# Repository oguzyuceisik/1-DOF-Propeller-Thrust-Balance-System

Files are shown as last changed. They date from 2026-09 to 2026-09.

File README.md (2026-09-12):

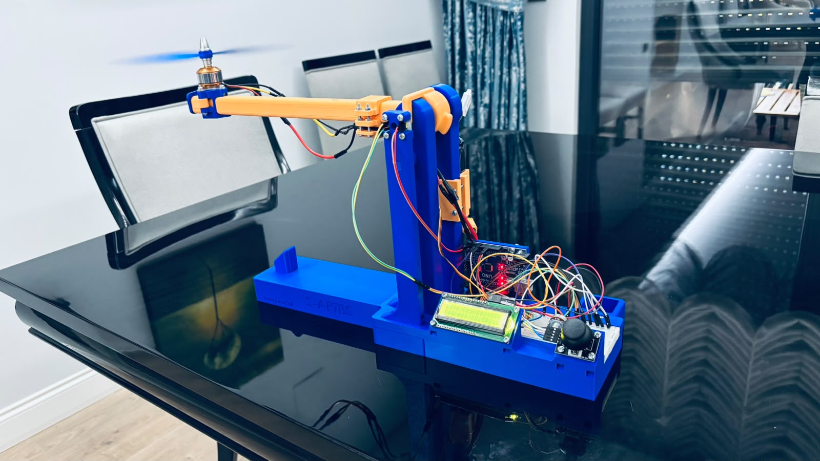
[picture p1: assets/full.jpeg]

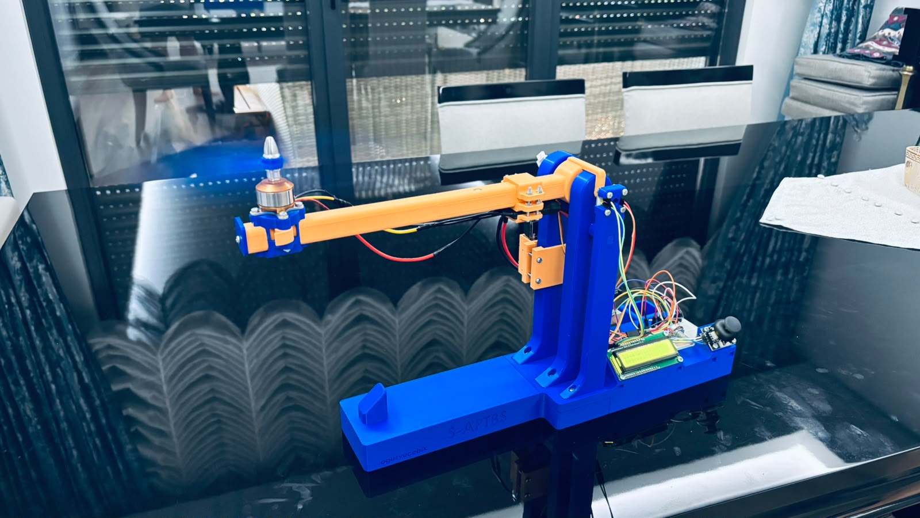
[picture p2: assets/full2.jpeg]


# 1-DOF-Propeller-Thrust-Balance-System

A 1-Degree-of-Freedom (1-DOF) closed-loop thrust balance arm controlled by a Brushless DC motor and an AS5600 12-bit magnetic rotary encoder, powered by an Arduino.

---

## Overview
This project demonstrates closed-loop attitude control of a thrust-balanced lever arm. A custom PID controller runs at a deterministic 50 Hz (`dt = 0.02s`), stabilizing the arm against gravity at any desired angle. System parameters ($K_p, K_i, K_d$, and Target Angle) can be adjusted in real time via a 2-axis analog joystick and an interactive 1602 LCD menu without interrupting the control loop.

---

## Features
- **Deterministic Loop Timing:** Control loop executes strictly at 50 Hz using non-blocking timer logic.
- **Custom Modular PID Implementation:** Written natively in C and wrapped as a C++ source file (`saptbsPID.cpp` / `saptbsPID.h`) for seamless compilation with the Arduino toolchain.
- **Integral Anti-Windup:** Prevents integrator saturation and aggressive overshoot using strict clamping boundaries ($\pm750\,\mu s$).
- **Base Actuator Offset:** Actuator output is mapped cleanly onto standard ESC pulse widths ($1000 - 2000\,\mu s$).
- **Live Telemetry & Interactive Menu:** Real-time angle monitoring and on-the-fly gain scheduling via a 1602 LCD and analog joystick.
- **Mechanical CAD Package:** Complete 3D printable files (`.stl`) and universal exchange models (`.step`) for the chassis, pivot bearings, M3 thread, and motor lever arm.

---

## Hardware Architecture

| Component | Specification | Function |
| :--- | :--- | :--- |
| **Microcontroller** | Arduino Uno | Main control loop, sensing, and ESC PPM generation |
| **Feedback Sensor** | AS5600 12-bit Rotary Encoder | Contactless angle measurement via I2C |
| **Actuator** | Brushless Motor + Propeller | Dynamic thrust generation |
| **ESC** | 30A Brushless ESC | Motor driving |
| **Interface** | 1602 Character LCD | Live telemetry display and tuning interface |
| **Input** | 2-Axis Analog Joystick Module | Menu navigation and runtime parameter updates |

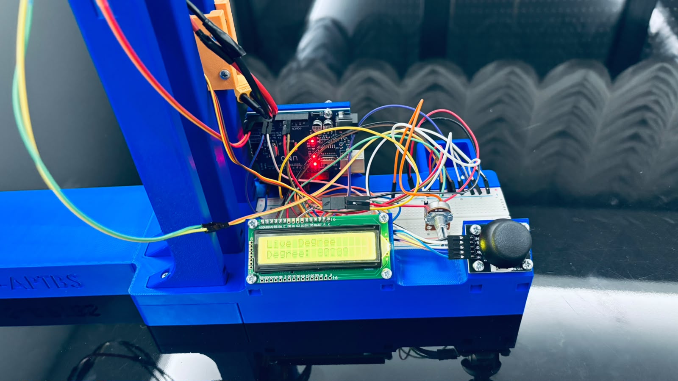
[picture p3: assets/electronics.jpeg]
Hardware

---

## Pinout Configuration

| Peripheral | Arduino Pin 
| **ESC Signal** | D6 
| **AS5600 SDA** | A4 
| **AS5600 SCL** | A5 
| **Joystick X-Axis** | A0 
| **Joystick Y-Axis** | A1 
| **Joystick Button** | D2 
| **LCD RS, EN** | D7, D8 
| **LCD D4 - D7** | D9, D10, D11, D12

---

## Mechanical & CAD Files
The complete physical assembly files are provided under the `/cad` directory:
- **`cad/stl/`**: Ready-to-print meshes for 3D printers (PLA or PETG recommended, %10-%15 infill).
- **`cad/step/`**: Universal CAD files for modification in SolidWorks.

---

## CAD PREVIEW

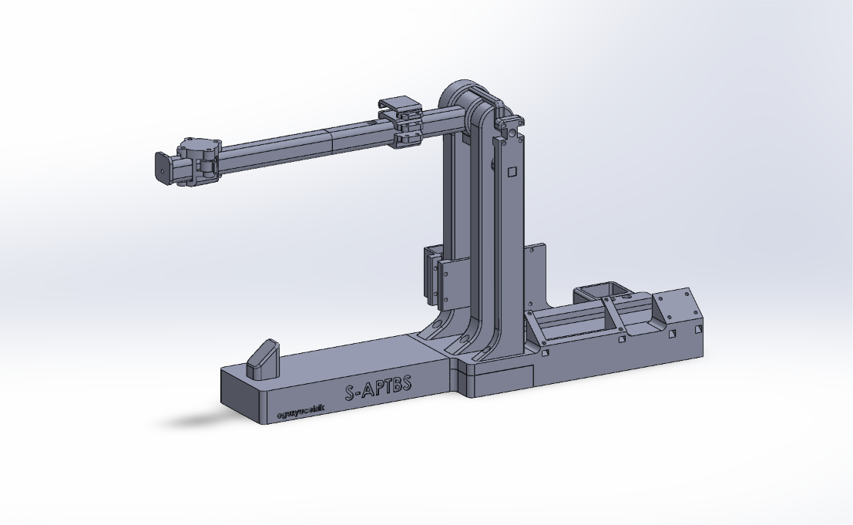
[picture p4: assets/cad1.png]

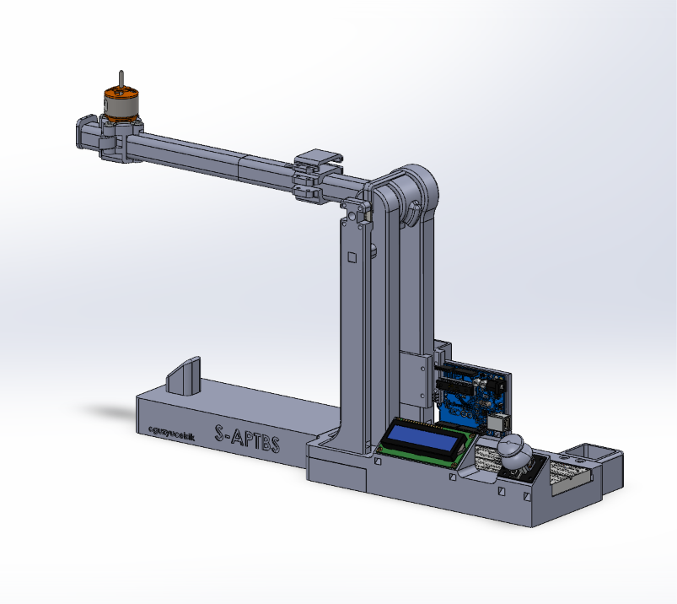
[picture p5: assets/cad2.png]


---

## Getting Started

1. Clone or download this repository.
2. 3D print the mechanical components from `/cad/stl` and assemble the pivot arm with the AS5600 diametric magnet axially centered.
3. Install the required Arduino libraries via Library Manager:
   - `Servo`
   - `Wire`
   - `LiquidCrystal`
   - `AS5600`
4. Connect the hardware according to the pinout table above.
5. Power the ESC with a 3S LiPo battery. The built-in 5V BEC supplies logic power to the Arduino and all connected peripherals.
6. Upload the `.ino` sketch to your Arduino board.
7. Wait 2 seconds during startup for the ESC arming sequence.
8. Use the joystick to navigate the LCD menu, adjust $K_p, K_i, K_d$ on the fly, and command target angles.

---

## MEDIA:
Demo Video (https://www.youtube.com/watch?v=CsmWMHaqUeA)

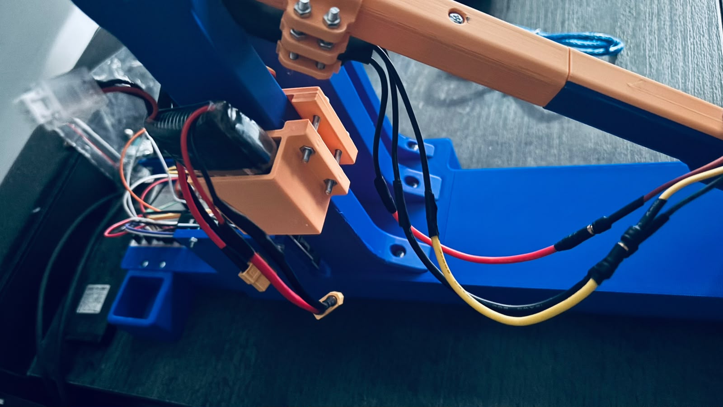
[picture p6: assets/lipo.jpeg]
LiPo Photo

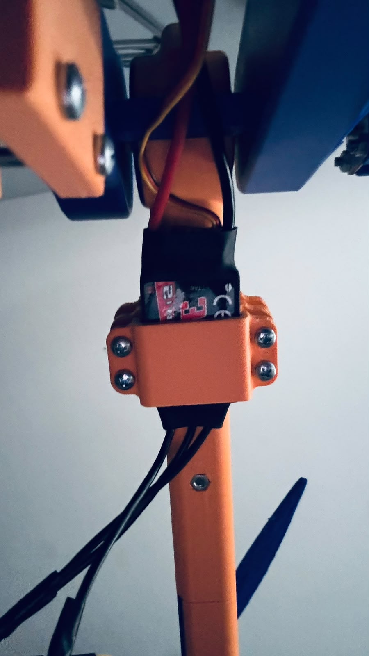
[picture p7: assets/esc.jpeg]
ESC Photo

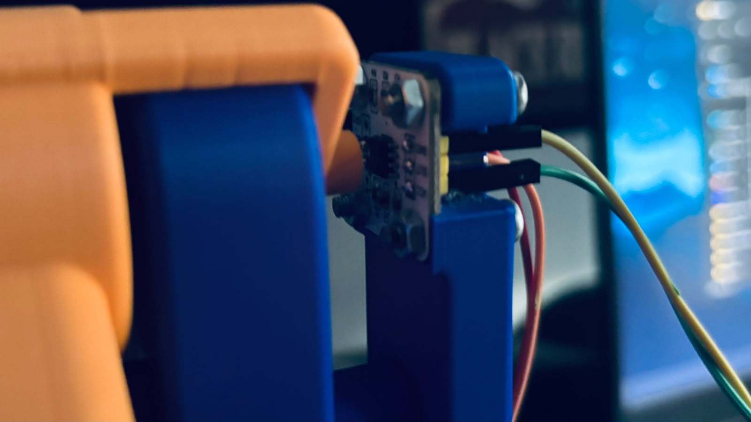
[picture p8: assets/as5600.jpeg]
AS5600 PHOTO


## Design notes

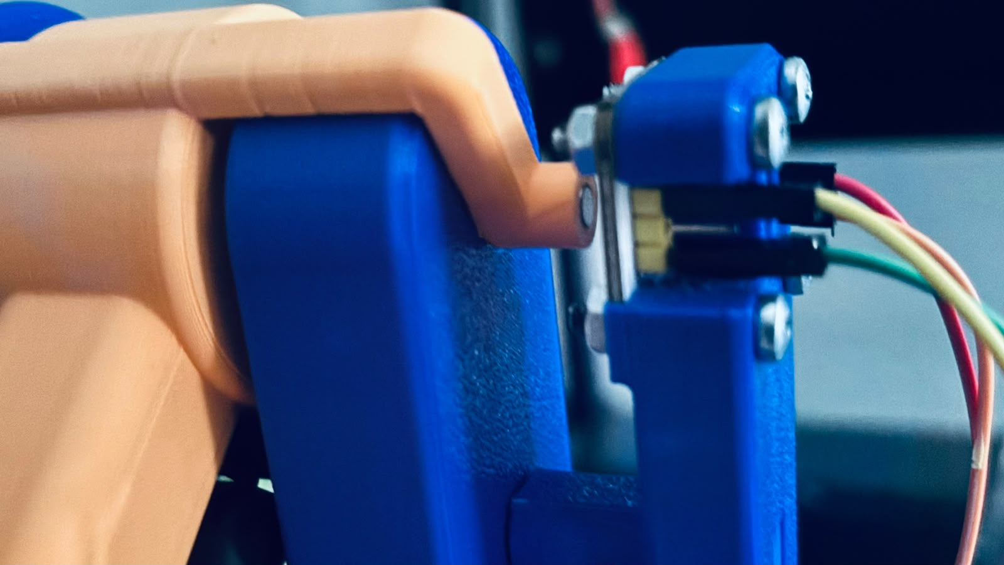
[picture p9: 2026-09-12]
assets/as5600 magnet.jpeg

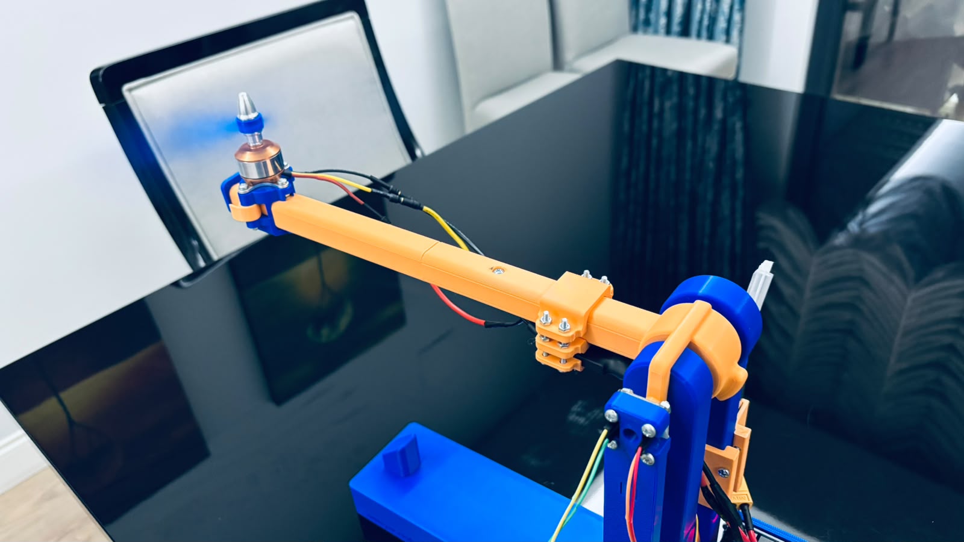
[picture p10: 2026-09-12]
assets/propeller.jpeg

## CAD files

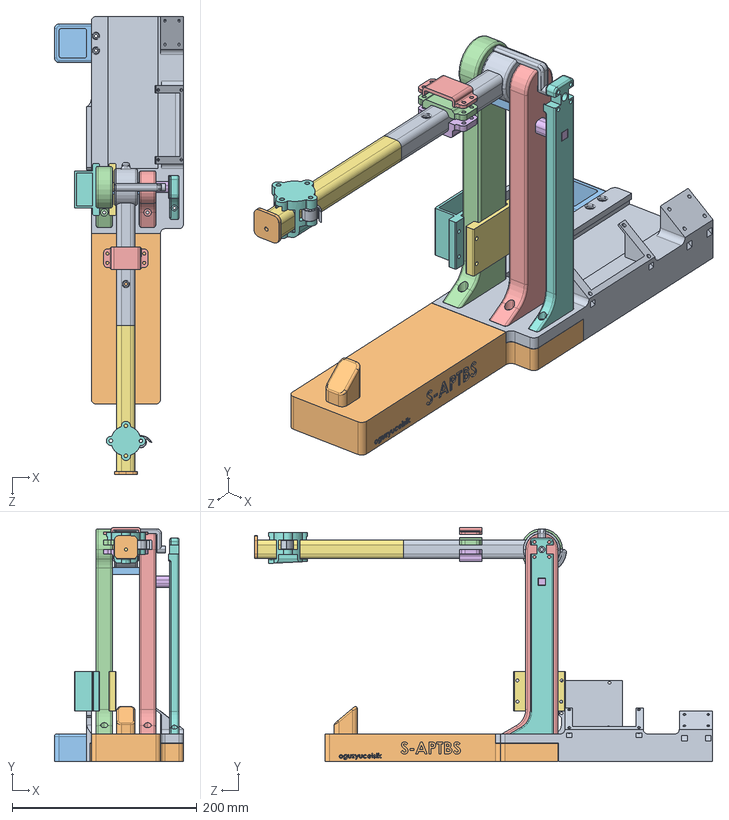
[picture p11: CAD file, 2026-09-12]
saptbsPID_CAD/SAPTBSassembly.STEP
140.0 x 254.0 x 496.4 mm
BaseParts
Leg1
6801ZZ_12x21x5_5972K154_Steel Ball Bearing_5972K154 x 2
LockIN
MotorBase
propellerLock
ArmLock
BatteryBed
ESCHolder
LiPoHolder

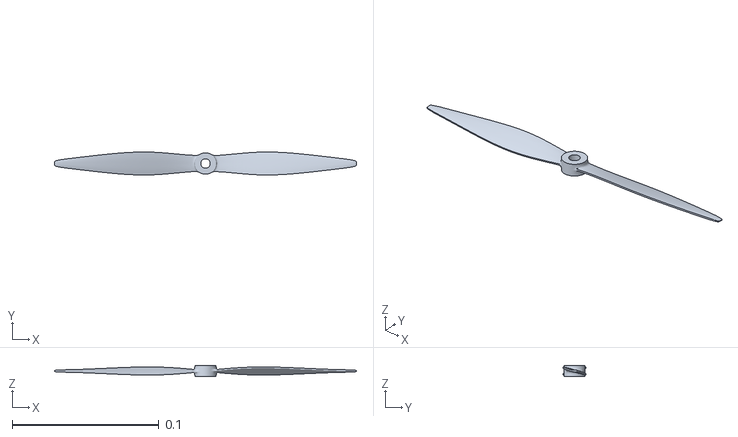
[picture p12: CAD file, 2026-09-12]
saptbsPID_CAD/propeller1.stl
0.206 x 0.0157 x 0.0075

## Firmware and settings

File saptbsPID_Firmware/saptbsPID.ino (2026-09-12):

#include "saptbsPID.h"
#include <Servo.h>
#include <Wire.h>
#include <AS5600.h>
#include <LiquidCrystal.h>


PIDsetup motor;
const uint8_t escPin = 6;

const uint8_t rs = 7;
const uint8_t en = 8;
const uint8_t d4 = 9;
const uint8_t d5 = 10;
const uint8_t d6 = 11;
const uint8_t d7 = 12;

const uint8_t xPin = A0;
const uint8_t yPin = A1;
const uint8_t jButton = 2;
int xVal;
int yVal;

int allow = 1;
int prev_allow = -600;

float kp = 6.f;
float kd = 3.0f;
float ki = 1.f;

float liveAngle = 0.0f;

float prev_kp = -600;
float prev_ki = -600;
float prev_kd = -600;
int prev_target = -600;

int i = 0;
int prev_i = -1;

String menus[5][2] = {{"Live Degree" , "Degree"},

                      {"Parameters", "Kp"},

                      {"Parameters", "Ki"}, 

                      {"Parameters", "Kd"}, 

                      {"Target", "Degree"}
};


byte upDownArrow[8] = {
  B00100,
  B01110,
  B11111,
  B00000,
  B11111,
  B01110,
  B00100,
  B00000
};

LiquidCrystal lcd(rs, en, d4, d5, d6, d7);

float target = 654.0f * (360./4095.);

AS5600 as5600;
unsigned long lasTime = 0;
unsigned long lastLCDTime = 0;
const int inputDelay = 250;


Servo esc;

void setup(){
  Wire.begin();
  as5600.begin();

  lcd.begin(16, 2);
  lcd.createChar(1, upDownArrow);
  pinMode(xPin, INPUT);
  pinMode(yPin, INPUT);
  pinMode(jButton, INPUT_PULLUP);

 Serial.begin(9600);

  esc.attach(escPin, 1000, 2000);
  pid_setup(&motor, kp, ki, kd,  2000, 1000);

  esc.writeMicroseconds(1000);
  delay(2000);

}

void loop(){

  lcdControl();
  
  unsigned long currentTime = millis();
  float dt = (currentTime - lasTime) / 1000.0f;

  if(dt >= 0.02f){
    lasTime = currentTime;

    float checkAngle = as5600.rawAngle();
    float wrongAngle = checkAngle + 1000;

      if (wrongAngle >= 4096) {
    wrongAngle -= 4096;
  } else if (wrongAngle < 0) {
    wrongAngle += 4096;
  }

    wrongAngle *=  (360./4095.);
    liveAngle = wrongAngle;
    
    float output = pid_calculate(&motor, target, wrongAngle, dt);
    esc.writeMicroseconds((int)output);
    Serial.println(output);
  }
}

void lcdControl(){
    unsigned long currentMillis = millis();
  
  xVal = analogRead(xPin);
  yVal = analogRead(yPin);

  if (currentMillis - lastLCDTime >= inputDelay){
  
    if(digitalRead(jButton) == LOW){
      allow*=(-1);
      lastLCDTime = currentMillis;
    }
  
  
    if(allow>0){
      if(xVal>800){
        if(i<4){
          i++;
          lastLCDTime = currentMillis;
        }else{
          i=0;
          lastLCDTime = currentMillis;
        }
      }else if(xVal<200){
        if(i>0){
          i--;
          lastLCDTime = currentMillis;
        }else{
          i=4;
          lastLCDTime = currentMillis;
        }
      }
    }
  
    if(allow<0){
      if(yVal < 200){
        if(i==1) motor.kp += 0.1;
        else if(i == 2) motor.ki +=0.1;
        else if(i==3) motor.kd += 0.1;
        else if(i==4) target -= 5;
        lastLCDTime = currentMillis;
      }else if(yVal > 800){
        if(i==1) motor.kp -= 0.1;
        else if(i == 2) motor.ki -=0.1;
        else if(i==3) motor.kd -= 0.1;
        else if(i==4) target += 5;
        lastLCDTime = currentMillis;
      }
    }

  }
  if(i!=prev_i || motor.kp!=prev_kp || motor.ki!=prev_ki || motor.kd!=prev_kd || target!=prev_target || allow != prev_allow){
    lcd.clear();
    lcd.setCursor(0, 0);
    lcd.print(menus[i][0]);



    lcd.setCursor(0, 1);
    lcd.print(menus[i][1]);
    lcd.print(": ");
    if(allow<0){
      if(i>0) lcd.write(byte(1));
    }



    if(i==0) lcd.print((-1)*(liveAngle - (654.0f * (360./4095.))));
    else if(i==1) lcd.print(motor.kp, 1);
    else if(i==2) lcd.print(motor.ki, 1);
    else if(i==3) lcd.print(motor.kd, 1);
    else if(i==4) lcd.print((-1)*(target - (654.0f * (360./4095.))));


    

    prev_i = i;
    prev_kp = motor.kp;
    prev_ki = motor.ki;
    prev_kd = motor.kd;
    prev_target = target;
    prev_allow = allow;
  }
}
